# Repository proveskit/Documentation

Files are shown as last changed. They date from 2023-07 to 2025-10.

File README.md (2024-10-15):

# Documentation
The Official Documentation of the PROVES kit. 

Our documentation is primarily hosted as a readthedocs site using the Material format.

# How to Contribute
Have updates you want to make to the documentation? Just open a new branch and make your desired edits in the `docs` folder. Once you're done just make a pull request back to main to have it reviewed before publishing to the main site. 

🚧👷‍♀️CURRENTLY UNDER CONSTRUCTION👷‍♀️🚧
## kit_part_list
This file illustrates all of the components that are shipped with the PROVES kit
## proves_kit_assembly_guide
This is the full assembly guide of the proves kit (currently under construction and updates, so some information may not apply, while other information may be missing)
## proves_kit_owners_manual
This is the owner's manual that comes with each new PROVES kit and provides information about the kit, as well as maintenance and operation of the satellite.

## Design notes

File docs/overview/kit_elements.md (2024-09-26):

# Elements of the Kit 
There are a few key components of the kit that align with the usual lineup of satellite sub-systems: 

- Structure 
- Electrical Power System
- Flight Controller 
- Communications
- Attitude Determination and Control
- Flight Software 
- Ground Support Systems

!!! "3D Visualizer"
    The team from Northeastern made this really cool [visualization](https://autode.sk/4eVLtiX) of the kit! You can even do an exploded view with it. 

<div class="grid cards" markdown>

-   :material-cube-unfolded:{ .lg .middle } __1U CubeSat Structure__

    ---

    The backbone of the CubeSat! Made out of bent 5052 Aluminum sheet metal, self clinching fasteners, and 3M 2216.
    
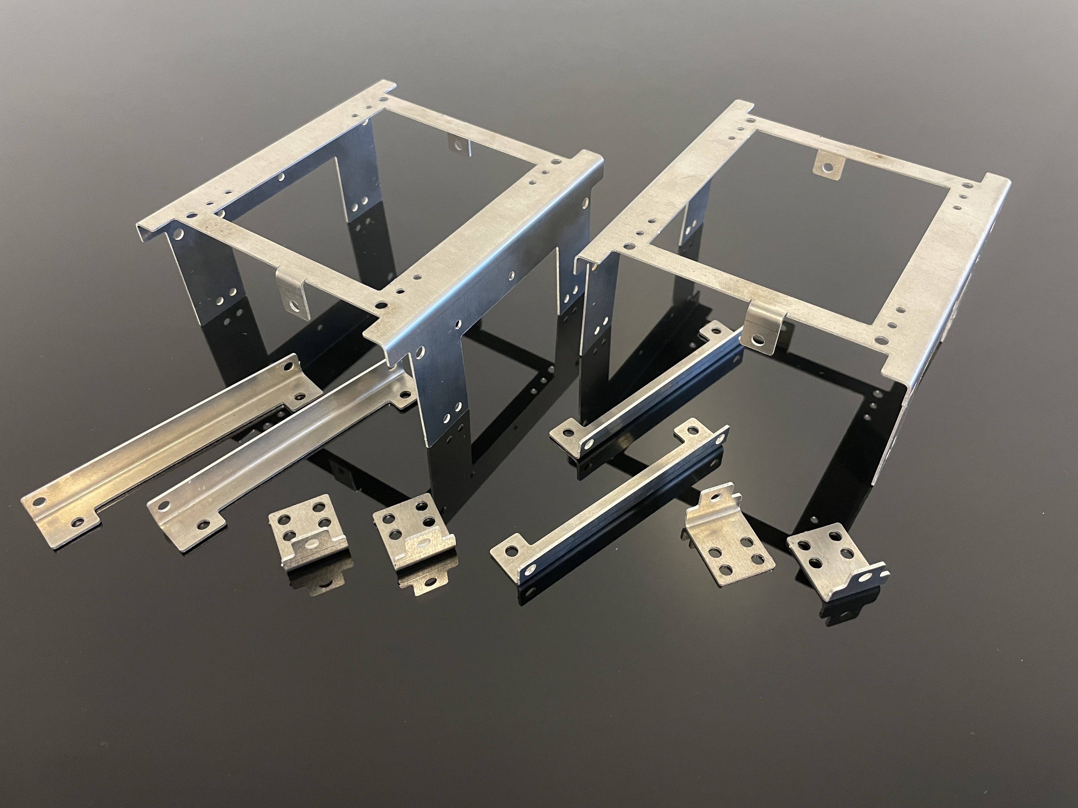
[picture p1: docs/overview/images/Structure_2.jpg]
PROVES Structure
    

    **Status:** V2.1 is Supported! <br>
    V1 has 3x Flight Heritage. 

    [:octicons-arrow-right-24: Core Documentation Link](https://docs.proveskit.space/en/latest/core_documentation/hardware/1U_structure/) <br>
    [:octicons-arrow-right-24: GitHub Repo Link](https://github.com/proveskit/1U_structure)

-   :material-battery-charging-100:{ .lg .middle } __Battery / EPS Board__

    ---

    The Battery / EPS (Electrical Power System) board maintains all of the juice that is needed to run the satellite.
    
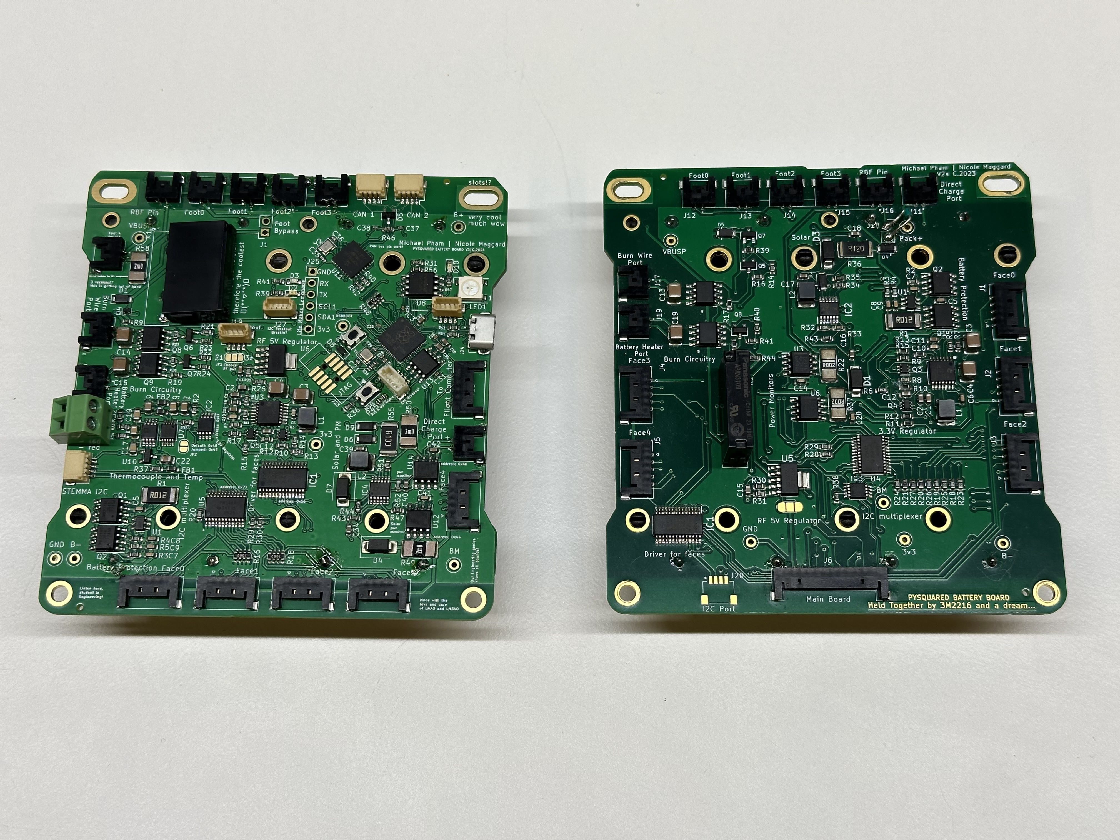
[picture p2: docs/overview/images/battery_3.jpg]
PROVES Battery Board
    

    **Status:** V3a/ V3b / V3c Supported! <br>
    V2 has 2x Flight Heritage. V3 introduces a redundant microcontroller.

    [:octicons-arrow-right-24: Core Documentation Link](https://docs.proveskit.space/en/latest/core_documentation/hardware/battery_board/) <br>
    [:octicons-arrow-right-24: GitHub Repo Link](https://github.com/proveskit/battery_board)

-   :fontawesome-solid-computer:{ .lg .middle } __Internal Flight Controller__

    ---

    The brain of the CubeSat, this is where the radio and main microcontroller lives on an internal board for temperature stability.
    
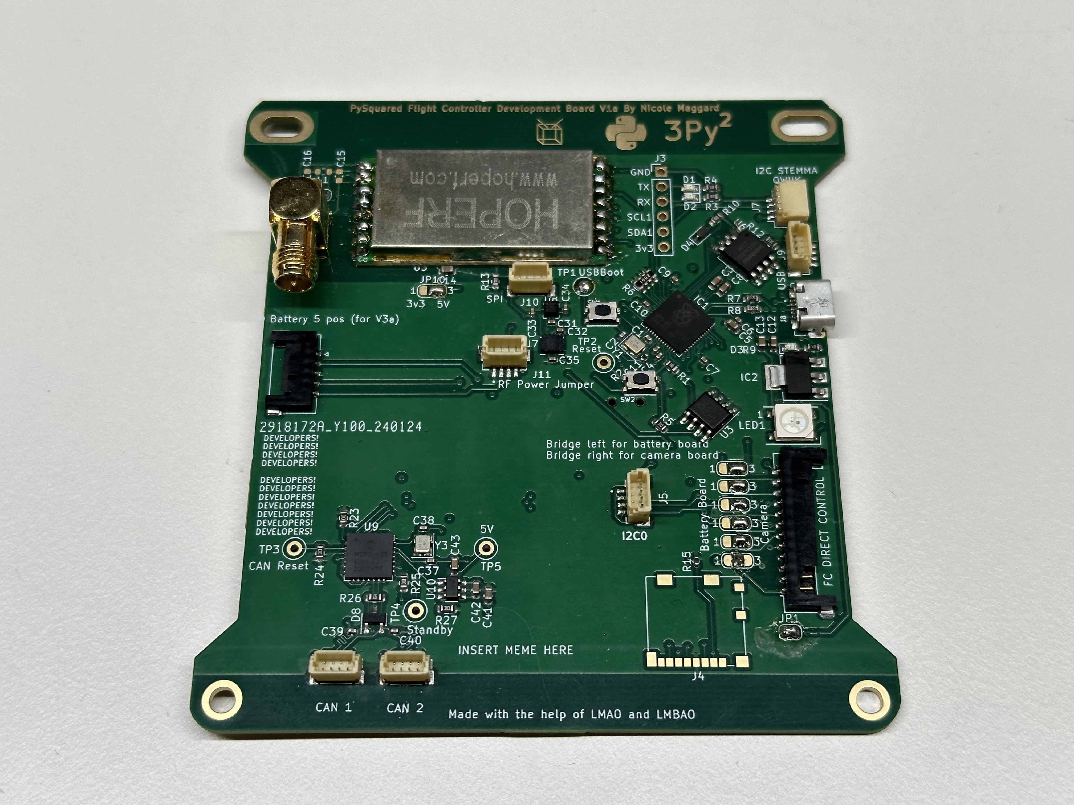
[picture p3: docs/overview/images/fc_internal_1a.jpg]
    

    **Status:** V4a and V4b Supported! <br>
    No Flight Heritage Yet. 

    [:octicons-arrow-right-24: Core Documentation Link](https://docs.proveskit.space/en/latest/core_documentation/hardware/FC_board/) <br>
    [:octicons-arrow-right-24: GitHub Repo Link](https://github.com/proveskit/flight_controller_board)

-   :fontawesome-solid-computer:{ .lg .middle } __External Flight Controller__

    ---

    The brain of the Yearling CubeSats! All mounted on the Z+ endcard of the satellite. Great for education maybe not for flight. 
    
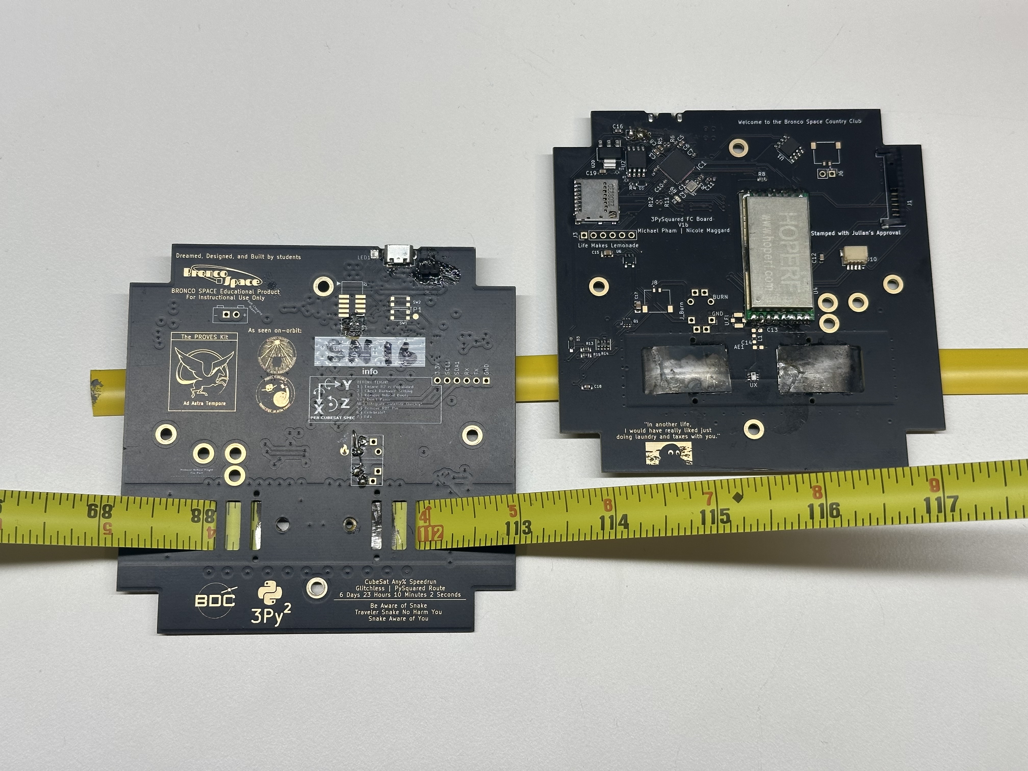
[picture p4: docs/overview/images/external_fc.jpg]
    

    **Status:** V2 is Supported! <br>
    V1 has 2x Flight Heritage. 

    [:octicons-arrow-right-24: Core Documentation Link](https://docs.proveskit.space/en/latest/core_documentation/hardware/FC_board/) <br>
    [:octicons-arrow-right-24: GitHub Repo Link](https://github.com/proveskit/flight_controller_board)

-   :material-solar-power-variant-outline:{ .lg .middle } __XY Solar Board__

    ---

    These are the solar panels that suround the X and Y faces of the CubeSat. They are a common part number for all of the faces to reduce cost!  
    
    PROVES Structure

    **Status:** V1 is Supported! <br>
    V1 has 2x Flight Heritage. 

    [:octicons-arrow-right-24: Core Documentation Link](https://docs.proveskit.space/en/latest/core_documentation/hardware/XY_solar_board/) <br>
    [:octicons-arrow-right-24: GitHub Repo Link](https://github.com/proveskit/solar_boards)

-   :material-solar-power-variant:{ .lg .middle } __Z- Solar Board__

    ---

    The Z- face of the satellite is a little special. It stil collects solar power, so it has cells on it. We also add unique interfacing elements.
    
    PROVES Structure

    **Status:** V2 is In Development! <br>
    V1 has 2x Flight Heritage. 

    [:octicons-arrow-right-24: Core Documentation Link](https://docs.proveskit.space/en/latest/core_documentation/hardware/Z_solar_board/) <br>
    [:octicons-arrow-right-24: GitHub Repo Link](https://github.com/proveskit/solar_boards)

-   :material-clock-fast:{ .lg .middle } __Camera Payload__

    ---

    The backbone of the CubeSat! Made out of bent 5052 Aluminum sheet metal. 
    
    PROVES Structure

    **Status:** V2.1 is Supported! <br>
    V1 has 3x Flight Heritage. 

    [:octicons-arrow-right-24: Core Documentation Link](https://docs.proveskit.space/en/latest/core_documentation/hardware/1U_structure/) <br>
    [:octicons-arrow-right-24: GitHub Repo Link](https://github.com/proveskit/1U_structure)

-   :material-clock-fast:{ .lg .middle } __Mechanisms__

    ---

    The backbone of the CubeSat! Made out of bent 5052 Aluminum sheet metal. 
    
    PROVES Structure

    **Status:** V2.1 is Supported! <br>
    V1 has 3x Flight Heritage. 

    [:octicons-arrow-right-24: Core Documentation Link](https://docs.proveskit.space/en/latest/core_documentation/hardware/1U_structure/) <br>
    [:octicons-arrow-right-24: GitHub Repo Link](https://github.com/proveskit/1U_structure)

</div>

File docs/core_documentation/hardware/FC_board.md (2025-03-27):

# Overview

<p align="center">Figure 1: The Internal Flight Controller Board</p>

The PROVES Kit Flight Controller is part of the PySquared architecture that harbors all of the satellites core operations. There are two variants of the Flight Controller, an internal variant and an external variant.

| Version | Flights | Status |
| --- | --- | --- |
| V0 | Unflown | Not Supported |
| V1 | Pleiades - Yearling, Pleiades - Squared | Legacy Support |
| V2 | Unflown | Unsupported |
| V3 | Unflown | Legacy Support |
| V4a (aka V1a Internal) | Unflown | Supported |
| V4b | Unflown | Supported |
| V4c | Pleiades - Orpheus | Supported |
| V5 | Unflown | In Development |

## Getting Started
!!! note 
    These instructions are valid for Flight Controller Boards V1a (Internal), V4a, V4b. V4c. 

1. If you do not plan on connecting a battery board, ensure that the ```JP1``` solder jumper is connected to enable powering the board via USB.
2. Solder on the Radio Module and an antenna or compatible SMA connector as needed.
3. Solder the JP10 V_RF Power selector as desired. 
    - Bridge the center pad to left for 3.3V or right for 5V. 
    - Generally, the smaller (more square) radio modules require 3.3V whereas the larger (more rectangle) radio modules require 5V. 
4. Plug in a USB Cable!
5. If a CircuitPython file system does not appear, you may have to flash the board with firmware. 
    - The most up to date firmware can be found [here](https://github.com/proveskit/flight_controller_board/tree/main/Firmware). 
    - If you have never installed CircuitPython before you can find instructions [here](https://learn.adafruit.com/welcome-to-circuitpython/installing-circuitpython).
6. Continue to the [PROVES Quick Start Guide](https://docs.proveskit.space/en/latest/quick_start/proves_quick_start/) for more!

## Utilized Parts

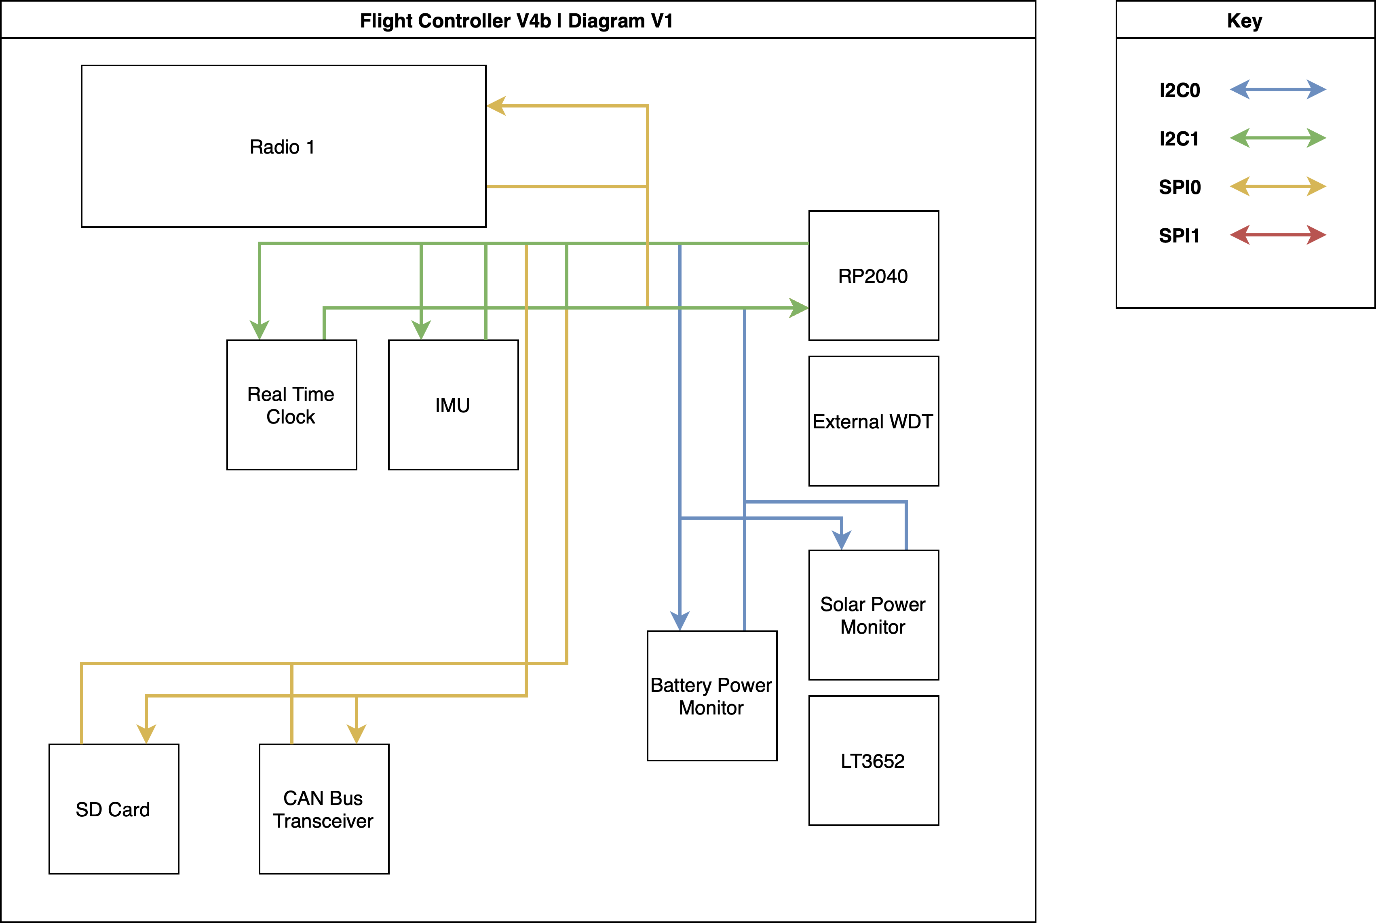
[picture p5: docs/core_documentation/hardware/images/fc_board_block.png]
Block Diagram


#### V4b Schematic
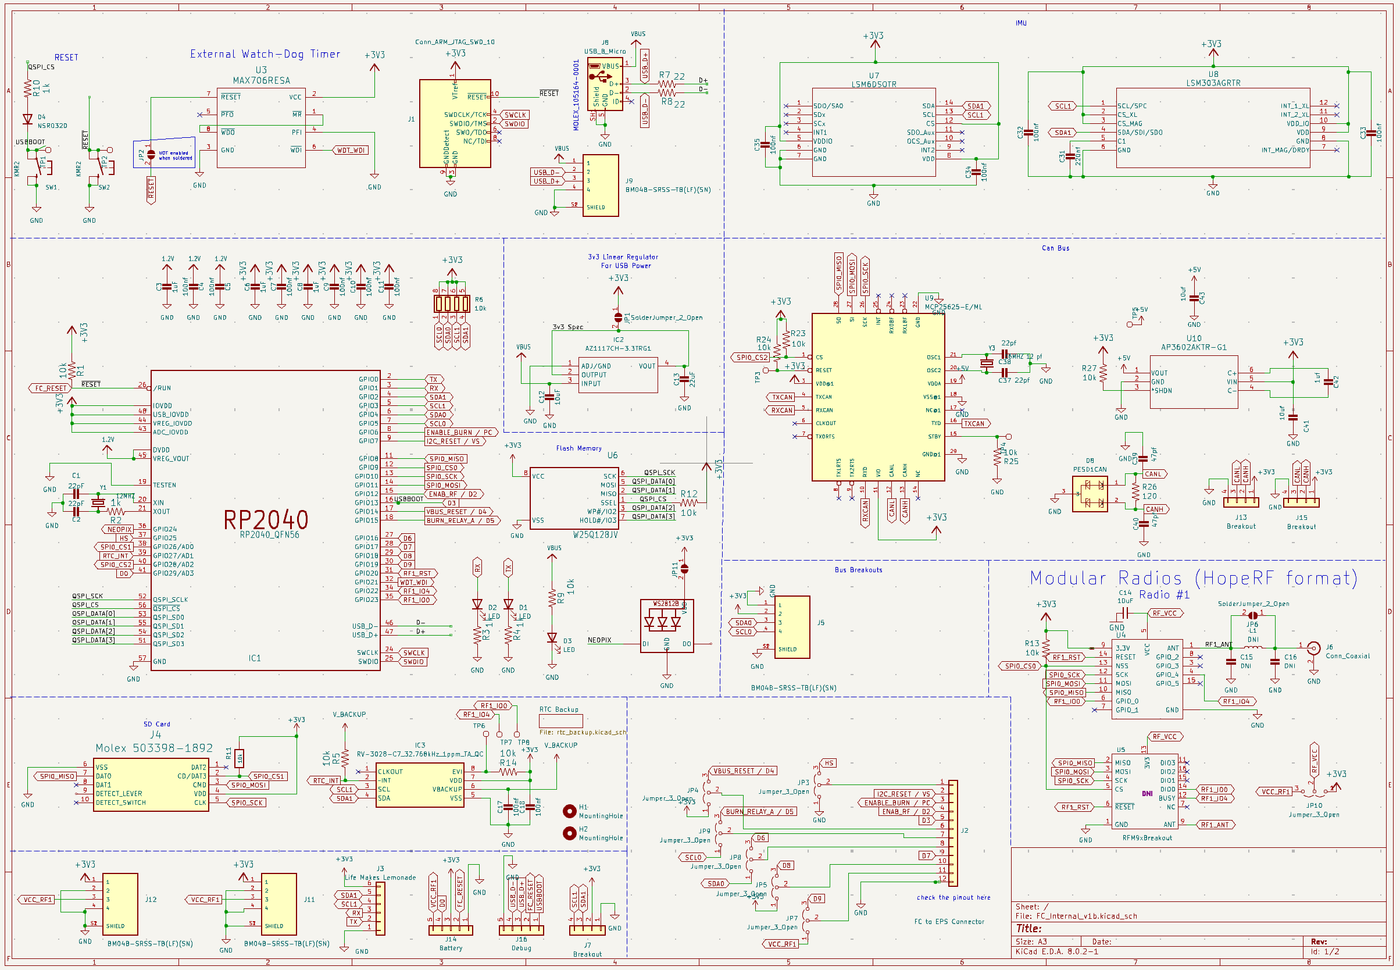
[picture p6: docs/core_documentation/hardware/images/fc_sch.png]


#### V4b Layout
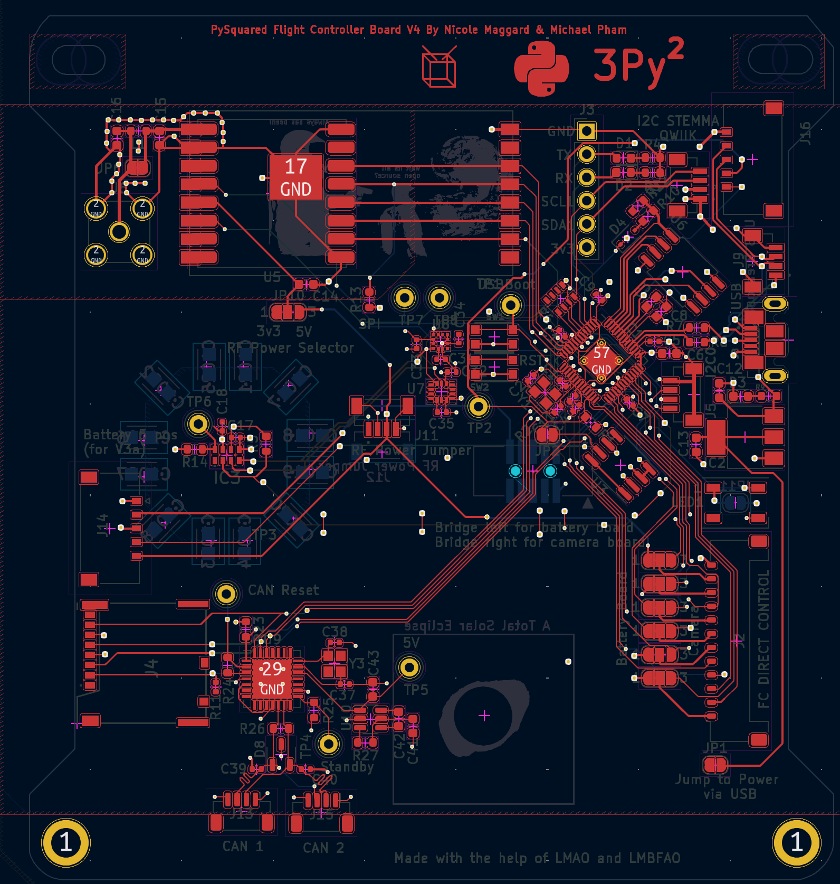
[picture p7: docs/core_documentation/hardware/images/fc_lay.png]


### RP2040 Microcontroller
The RP2040 is a powerful and versatile microcontroller developed by Raspberry Pi Ltd. It features a dual-core ARM Cortex-M0+ processor running at 133 MHz, 264 KB of SRAM, and flexible digital interfaces. The RP2040 was selected for use in the PROVES Kit thanks to its industry leading $1 price and abundance during the global chip shortage. Today we continue to use it thanks to the growing community of users worldwide. 

Key features of the RP2040 include:

- Dual-core ARM Cortex-M0+ processor
- 264 KB of on-chip SRAM
- Support for up to 16 MB of off-chip flash memory
- Programmable I/O (PIO) blocks for flexible interfacing
- USB 1.1 host and device support
- Low power consumption

The RP2040 can be programmed using various languages, including C, C++, MicroPython, and CircuitPython. Currently we support programming in CircuitPython or C++ (through the PicoSDK). 

### RFM98PW 433 MHZ Radio Module
To communicate between satellites or to ground stations. This module was selected based on its flight heritage on the PyCubed lineage of CubeSats. The RFM98 specifically supports the 435Mhz - 438Mhz range that is allocated to amateur radio satellites. The footprint on the board is a hybrid footprint that also allows the mounting of an RFM95 radio module that can operate in the ISM 915Mhz band as well. 

### RV-3028-C7 Real Time Clock (RTC)
The RV-3028-C7 is an I2C connected real time clock module that provides UNIX time in seconds, minutes, hours, date, month, year and weekday counters. The RTC also has the ability to deliver microcontroller interupts based on a predetermined time or through an external event. The primary use case for the RTC onboard the flight controller board will be for pin alarms that can be used to either wake up the microcontroller from a preset sleep period or alert the microcontroller to send a radio message on a predetermined schedule. This is the same IC as the RTC used on the OreSat C3. 

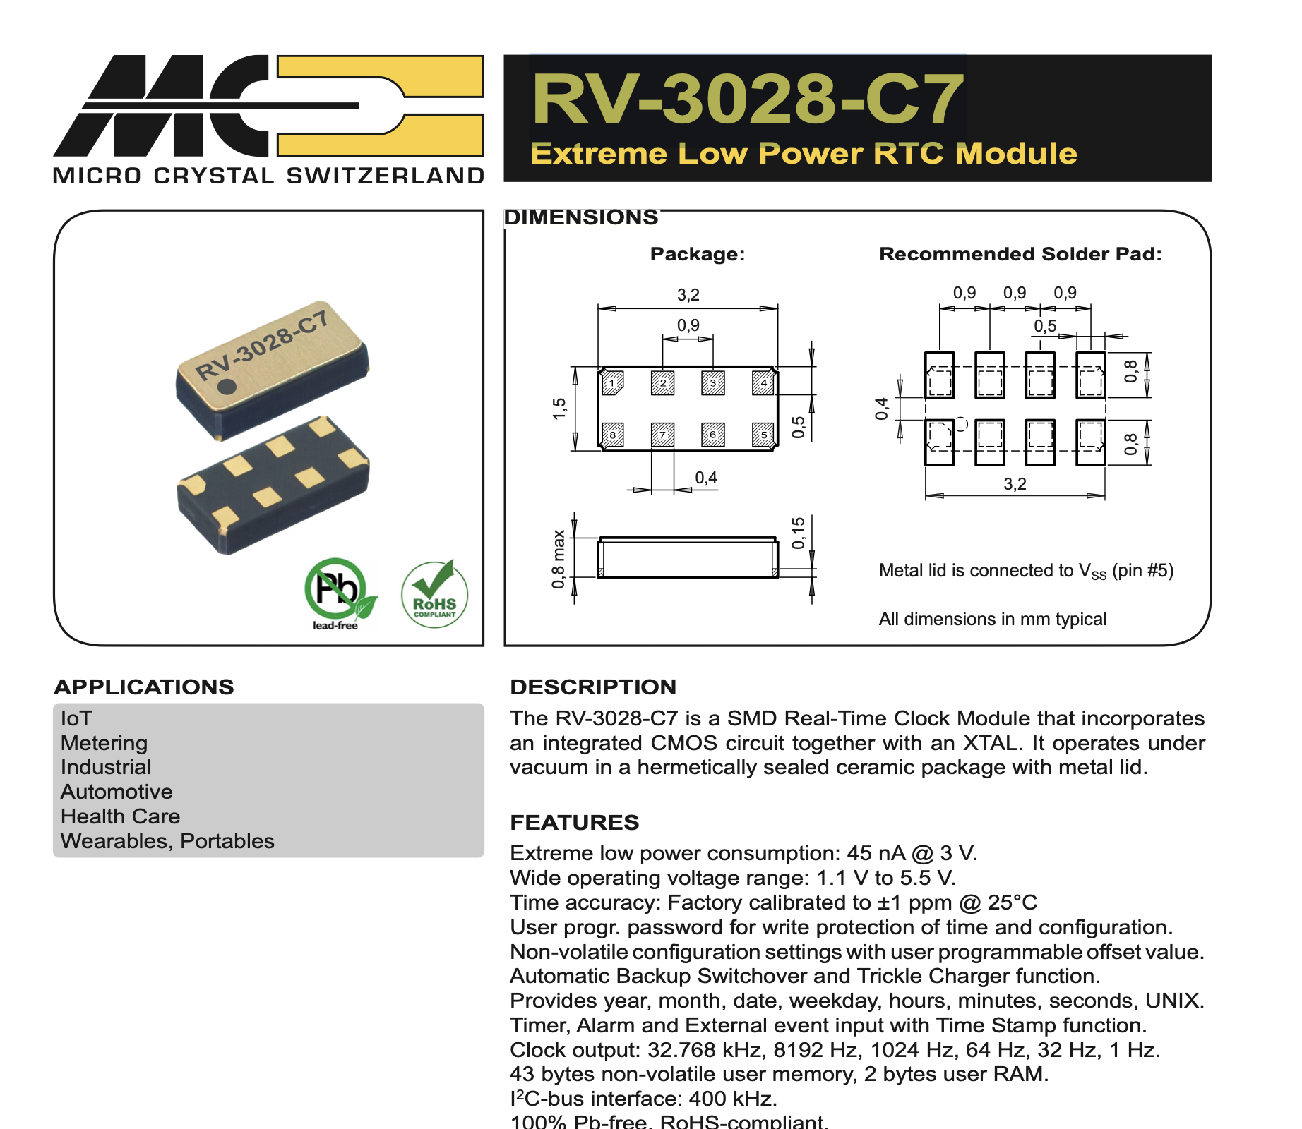
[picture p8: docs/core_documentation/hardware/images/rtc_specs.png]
RTC Spec Sheet


[Datasheet](https://www.microcrystal.com/fileadmin/Media/Products/RTC/Datasheet/RV-3028-C7.pdf)

[Application Guide](https://www.microcrystal.com/fileadmin/Media/Products/RTC/App.Manual/RV-3028-C7_App-Manual.pdf) 

Blake from the TXST Space Lab did some cool testing to make sure that the RTC doesn't start drifting from real time in this [GitHub Issue](https://github.com/proveskit/pysquared/issues/186)

### VL6180 LiDAR
To detect antenna deployment. As of V4 of the flight controller board the VL6180 is instead connected to the battery board to work in concert with the burn wire circuit. 

### MOLEX Micro SD Card Reader
Any SD Card up to 16Gb is supported by CircuitPython. We recommend using [Sandisk Industrial SD Cards](https://www.mouser.com/datasheet/2/669/SanDisk_Industrial%20Grade%20SD%20%20MicroSD%20Product%20Brief-805940.pdf) for flight, but any SD card will do for ground testing. 

### MAX706RESA Watch Dog Timer
To ensure the Flight Controller stays operational, this is a component that is borrowed from the PyCubed and is the watchdog circuit for V4b and earlier flight controller boards.

### TLV1704 Radiation Tolerant Watchdog Circuit
[Datasheet](https://www.ti.com/lit/ds/symlink/tlv1704.pdf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)
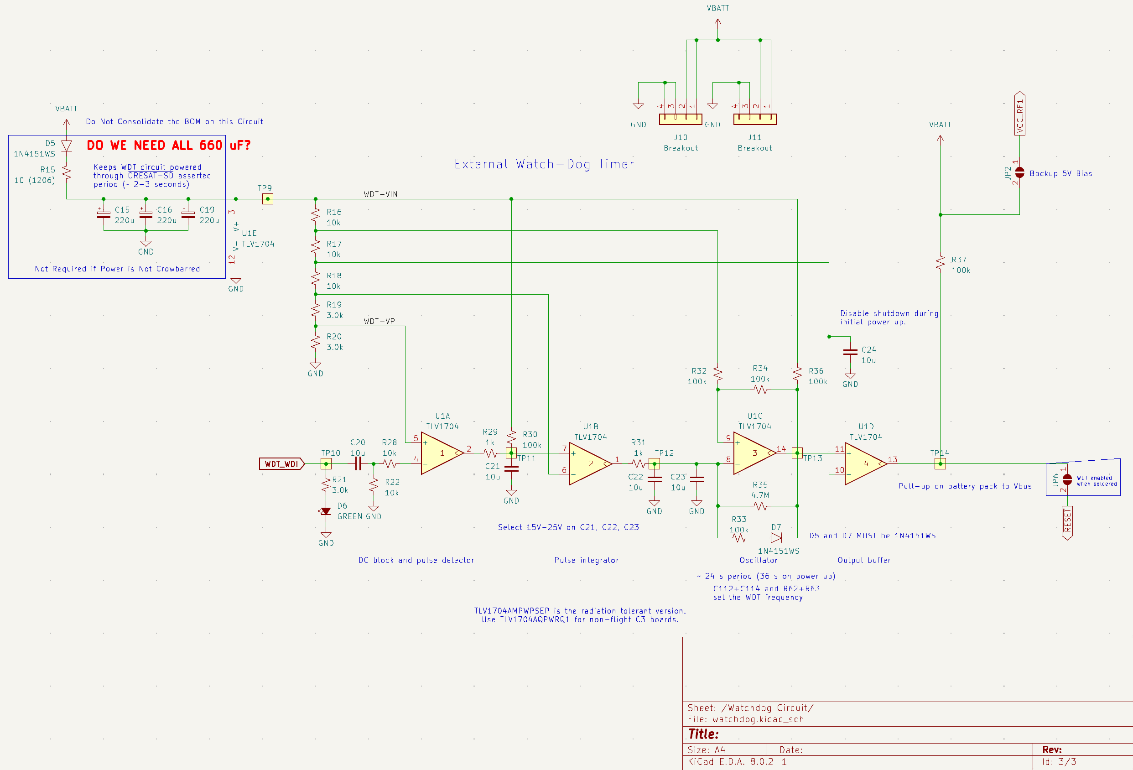
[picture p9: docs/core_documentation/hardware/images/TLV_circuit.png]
TLV Circuit Schematic


Starting with **FC Board V4c** and higher we swapped out the MAX706RESA with a windowed watchdog circuit based on the TLV1704 comparator network from Ti. This particular design has the option of swapping the standard TLV1704 with a TLV1704 **-SEP** (Space Enhanced Part) which is radiation tolerant (note there is a difference between *tolerant* and *hardened*). 

#### Using the Watchdog Circuit
By default this watchdog circuit expects a voltage pulse along the `WDT_WDI` line from the RP2040 every 26s (or 54s on cold start). If no pulse comes through then a reset will be triggered by pulling the `RESET` line low. 

!!! bug "V4c InspireFly Special Triggers too Fast!"
    
    A known issue for V4c InspireFly Special boards is that when powered up the WDT circuit actually triggers a reset approximately every 5s rather than the designed 26s. This was due to a BoM consolidation mistake when manufacturing the boards and will be corrected in future production runs.

    Find out more on [this GitHub Issue](https://github.com/proveskit/flight_controller_board/issues/24).

In order for that `RESET` signal to actually be sent, a bias voltage (5V or greater) must be provided through the `J10` or `J11` breakout connectors. For the signal to actually make it through to the RP2040, then the JP6 solder jumper on the front of the FC board needs to be connected. 

### AZ1117CH 3.3V Linear Voltage Regulator
To power the Flight Controller without a Battery Board. This linear regulator uses the 5V V_Bus line from the USB port and supplies 3.3V when the JP1 solder jumper is connected.

## Change Log
The change log keeps track of major differences between the various versions of the flight controller board. 

### Version 4
With the introduction of V4 Flight Controller Boards (also known as V1 Internal Flight Controller Boards) we moved the main flight controller from being the inside of an exterior panel to its own dedicated board on the inside of the satellite. This was done to better protect the main avionics package from thermal and radiation effects. 

#### V4a
The `a` variant of the flight controller board introduced some layout changes and part package swaps from the base V4. No fundamental functionality was changed in this version. 

#### V4b
The `b` variant of the board repositioned certain connectors, added a debug Picolock, variant added a Real Time Clock circuit to the board. 

#### V4c 
The `c` variant of the board adds the OreSat based watchdog timer circuit to try and better defend against radiation upsets. There are two sub-varients of this board which are the `Express` (as seen on Pleiades - Orpheus) and `InspireFly Special` (as seen on InspireFly). 

## Power Consumption Characterization
Notes on the FC board power consumption and attempts to reduce power consumption through underclocking the MPU are noted in [this GitHub Issue](https://github.com/proveskit/flight_controller_board/issues/22).

## Known Issues
- Microcontroller and radio possibility have a high suspectibility failure due to thermal and radiation effects. In a future version imrpoved placement and redundancy will be implemented to protect these core components from those effects.  
- Antennas are very annoying to install and may also be suceptible to failure due to thermal effects. 

### V5 Dev Board Errata

- LM2901 needs to the the B variant for open collector use
    - When the watchdog load switch is enabled it causes a hard reset of the board
- SPI1 and SPI0 are using the same hardware peripheral whoops
- For a currently unknown reason the load switches go into FAULT when connected to the solar panel boards
    - The solar panels function without overcurrent when powered by an independent supply
    - Removing the current limit resistor seems to have no effect
    - This is now SOLVED. Current limit is pulled up instead of down
- MUX_RESET is not connected
- When solar face is power cycled quickly it latches the TCA I2C bus low. Requires an unplug and replug
- Fire Deploy A and Fire Deploy B need to be connected to burn.
- 555 Timer Reset Circuit creates a boot loop when used.

## Troubleshooting

## Serial Number Tracking 

- FCV4c_0010: RFM98PW Sent to InspireFly
- FCV4c_0011: RFM98PW Sent to InspireFly
- FCV4c_0016: RMF98PW Sent to InSpireFly with -SEP Watchdog
- FCV4c_0006: RFM98PW Sent to Texas State
- FCV4c_0008: RFM98PW Sent to SlugSat
- FCV4c_0009: RFM98PW Sent to Northeastern
- FCV4c_0012: RFM98PW Sent to Columbia
- FCV4c_0017: No Radio Sent to Mt. SAC

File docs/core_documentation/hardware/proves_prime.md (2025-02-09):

# The PROVES Prime Mainboard
Trying out a single board implementation for the PROVES Kit again! 

## Design Objectives
The core goal of the PROVES Kit is to provide a low cost and accessible means of getting working hardware and software in outer space. We interpret that goal as the following:  
```
Having a satellite architecture that:
- Costs approximately $1000 
- Can be built in one day and 
- Will die when it deorbits. 
```
Depending on how the Pleiades - Orpheus mission goes, V1.5 of the kit may have already acomplished that! There is a big problem with V1.5 though, technical debt from patchwork development over the last year has made it rather complicated and not easy to replicate outside of the Bronco Space Lab. As a result, here we are trying to semi clean sheet a V2 design of the kit for much quicker and easier builds! 

## Planned Changes From V1.5 

Major Updates: 
- Returning to a PyCubed Style Mainboard / Battery Board Scheme 
- Removing the secondary microcontroller 
- Reworking the electrical power subsystem
- Adding options for multi-radio setup 
- Rework of the connectors and harnessing system 
- Designing for scalability with larger and more complex payloads

## Dev Logs
This section is for a running log of development activities! The goal is with regular "dev diary" sort of updates to be able to track the logic behind alot of the PROVES Prime Design Decisions. 

### February 9, 2025 | Expanding on the Minimum Viable Satellite
It has been a couple slower than expected weeks for development! The main thing we have to share at this point is that we've slightly refined what we are thinking of when we talk about the MVS. The attatched block diagram helps explain what our current thinking is.

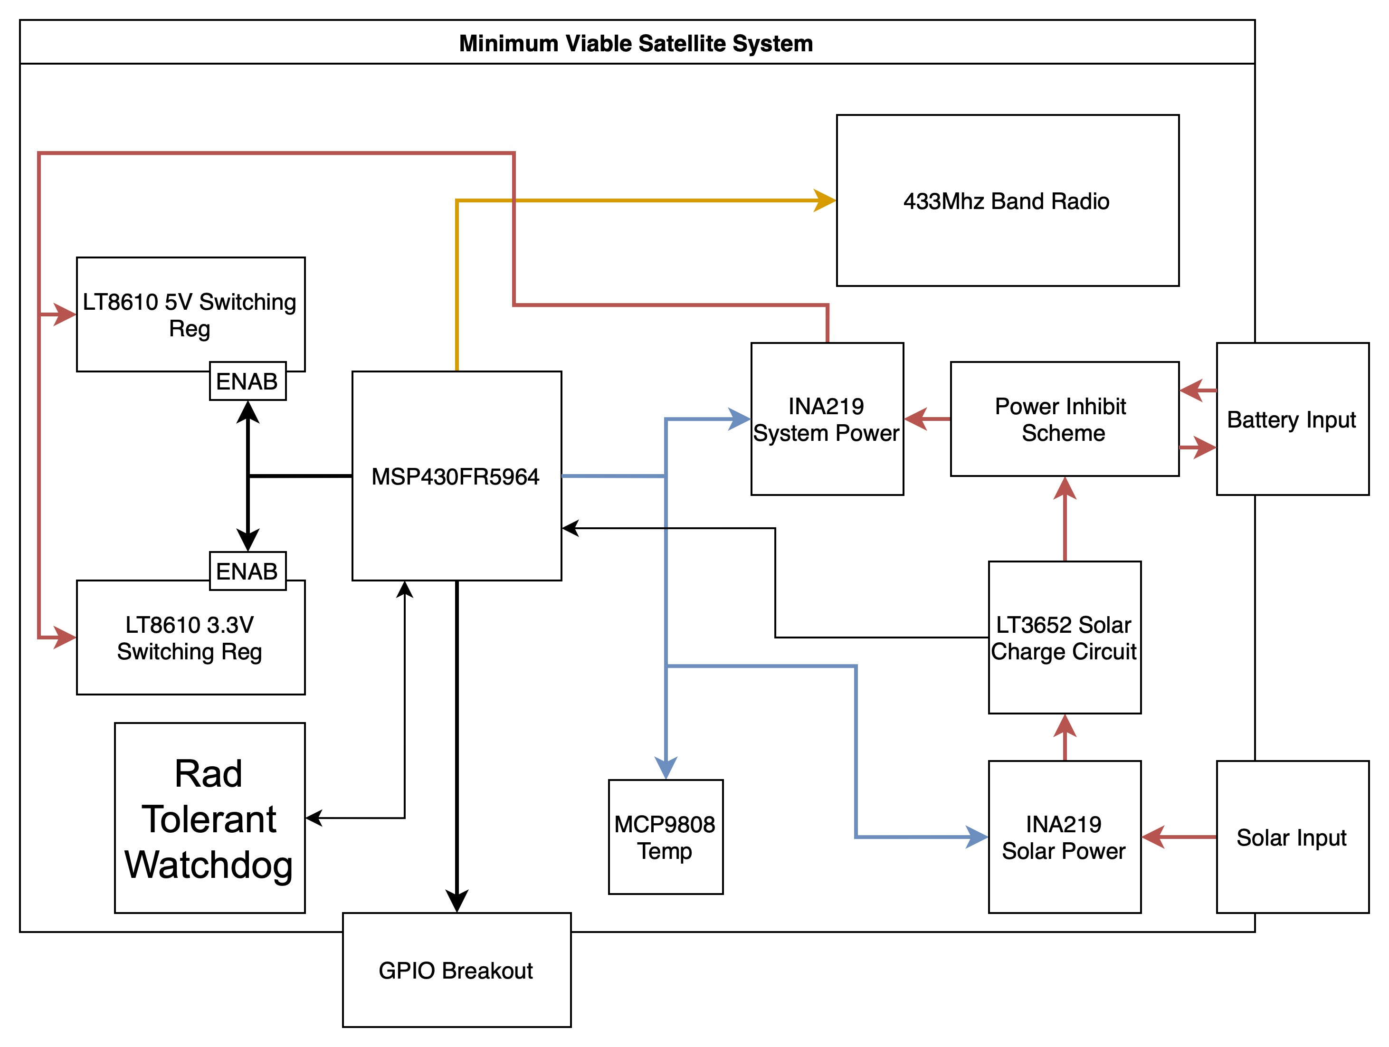
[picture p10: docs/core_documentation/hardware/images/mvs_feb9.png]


The general concept here is that the MSP430RF used at the core of the MVS system will have the ability to monitor and manipulate the overall power distribution to the rest of the satellite system using its GPIO. In a way, this chip is now going to be the supervisor that ensures all of the satellite's subsystems are behaving. Having this be a seperate chip rather than rolling it into the RP2350 frees up I/O and simplifies the software that needs to run on the RP2350 so it can focus on the mission needs rather than satellite oversight.

### January 26, 2025 | The First Devlog! 
Okay so this is where we're starting with trying to actively track the development of this board! Currently the two design contributors are Michael Pham, Rachel Rakushkin, and the Hacker LMBFAO. At this stage we have some preliminary component select and schematic migration from the existing PROVES boards complete. 

#### Overall Architecture Plan
Right now our thought is to run a hybrid architecture where there is a ultra-low power microcontroller (the MSP430FR line most likely) that runs a "Minimum Viable Satellite" (MVS) alongside an RP2350 microcontroller that will run most of the satellite systems and interface with payload data collection. The attatched block diagram reflects the thinking here. 

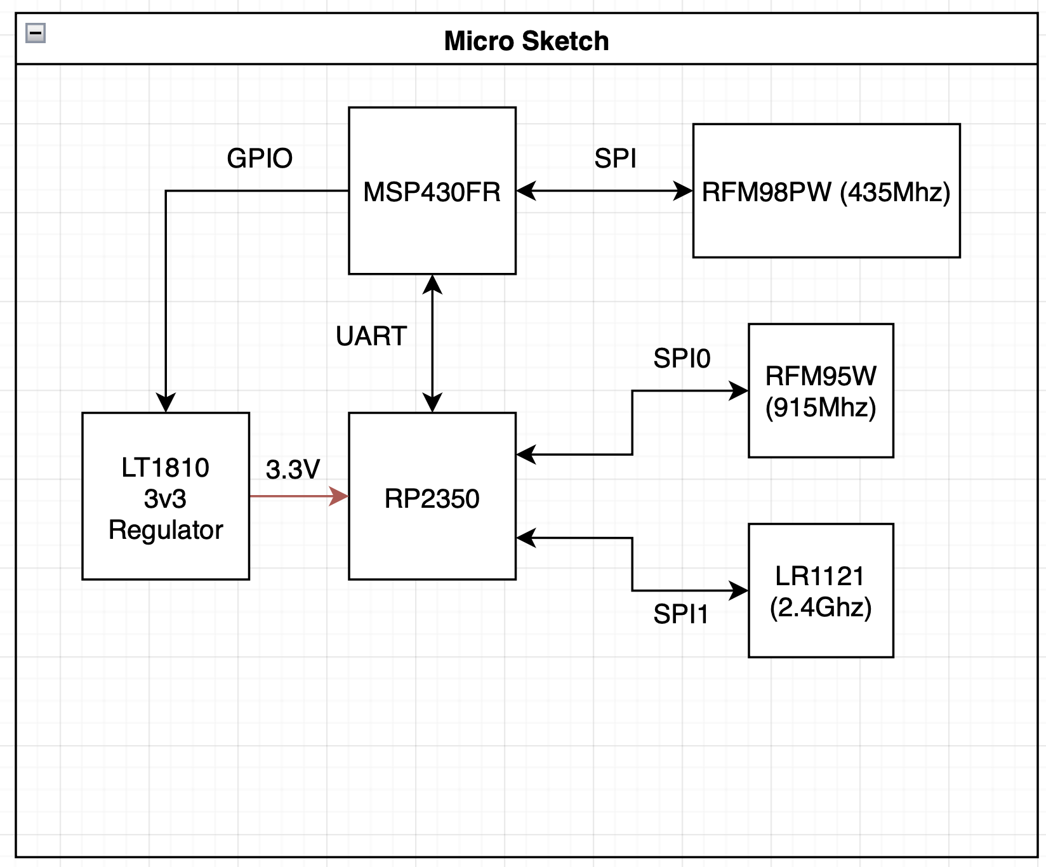
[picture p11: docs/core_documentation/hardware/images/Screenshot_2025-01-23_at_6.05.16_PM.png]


The big idea here is that we have a somewhat modular MVS section of the board, that is able to support the most essential satellite systems in the safest and simplest way possible, running alongside the core systems connected to the RP2350, which will do all of the mission data collection and satellite management. The thought is that we can rely on the MVS at all times to provide a satellite beacon with the most important satellite metadata while allowing the core systems to run a little more fast and loose with the RP2350.  

The MSP430 (despite being a pretty ancient microcontroller) has plenty of proven heritage in spaceflight and industrial applications. Particularly the **FR** varients use FRAM which lends an increased resistance to radiation upsets and permits the microcontroller to run a very low power. As a center of the MVS, this microcontroler will have access to the 435Mhz band UHF radio, the system and solar power monitors, and GPIO that connects to the enable pins of the 3v3 and 5v regulators. That last element giving the MVS the ability to "turn the sateliite off and on again" if it is ever needed. This system will then interface with the RP2350 core through a UART connection. 

#### LT8610 Switching Voltage Regulator Designs
One of the other big changes from all previous PROVES Kits is that we leaving behind the TPS5422X series of switching voltage regulators and instead using the LT8610 series. We get a minor improvement in efficiency and compactness by doing this, but one of the biggest reasons we are making this switch is because there seems to be pretty promising raditation data from ESA on these chips!

[Link to ESA Radiation Database](https://esarad.esa.int/)

Rachel led the design of both the 3.3V and 5V switching regulator schematics. The preliminary schematics are attatched here. 

[!Rachel's Schematics](images/lt8610_jan.PNG)

## Quick References
This is a section for storing quick reference images and notes regarding the design of the PROVES Prime Mainboard. 

### RP2350 Pin Definitions
!!! "Source"
    https://datasheets.raspberrypi.com/rp2350/rp2350-datasheet.pdf

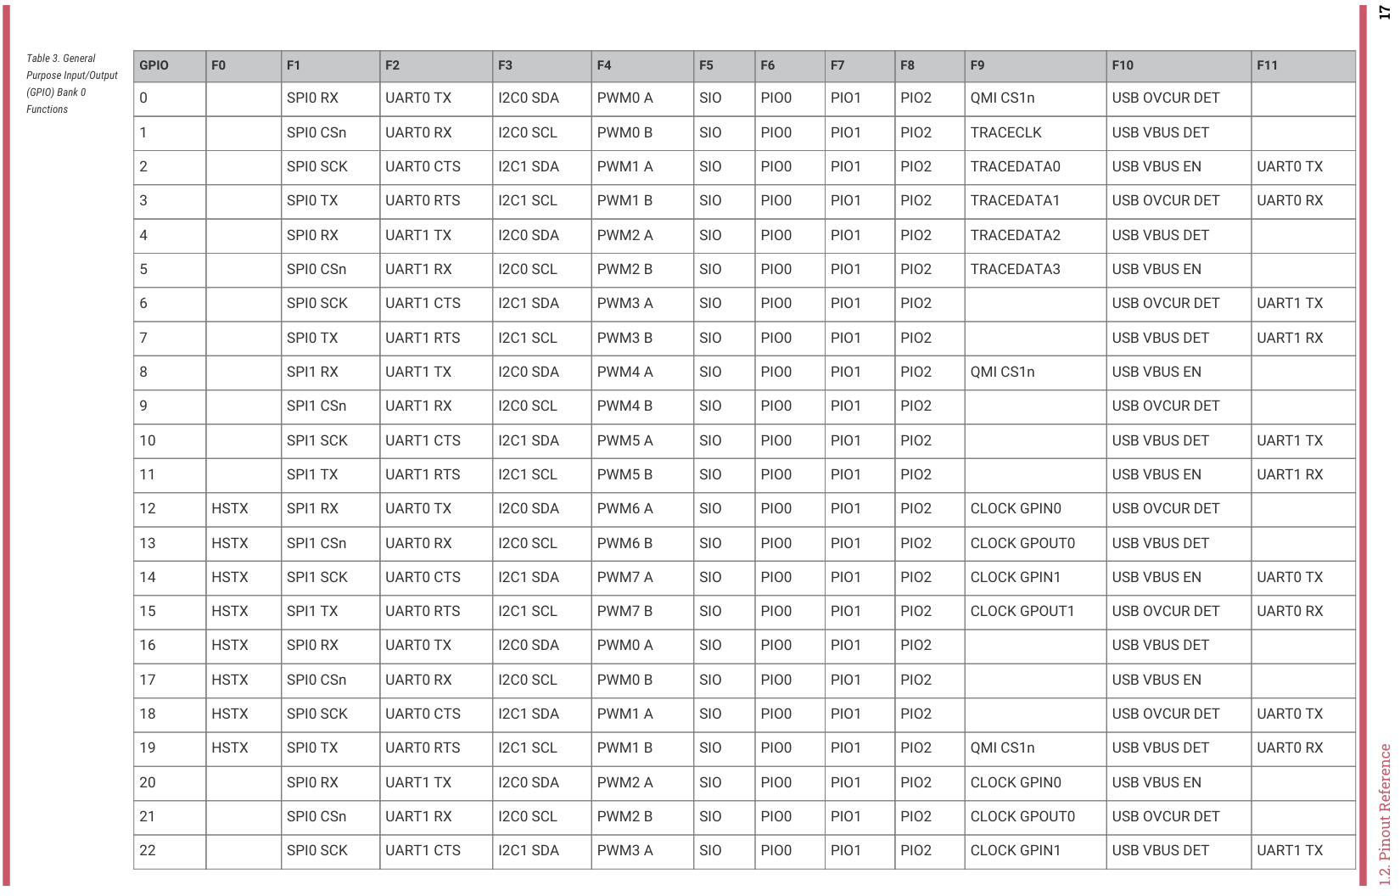
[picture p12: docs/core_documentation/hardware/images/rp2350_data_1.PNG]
RP2350 Pins 1

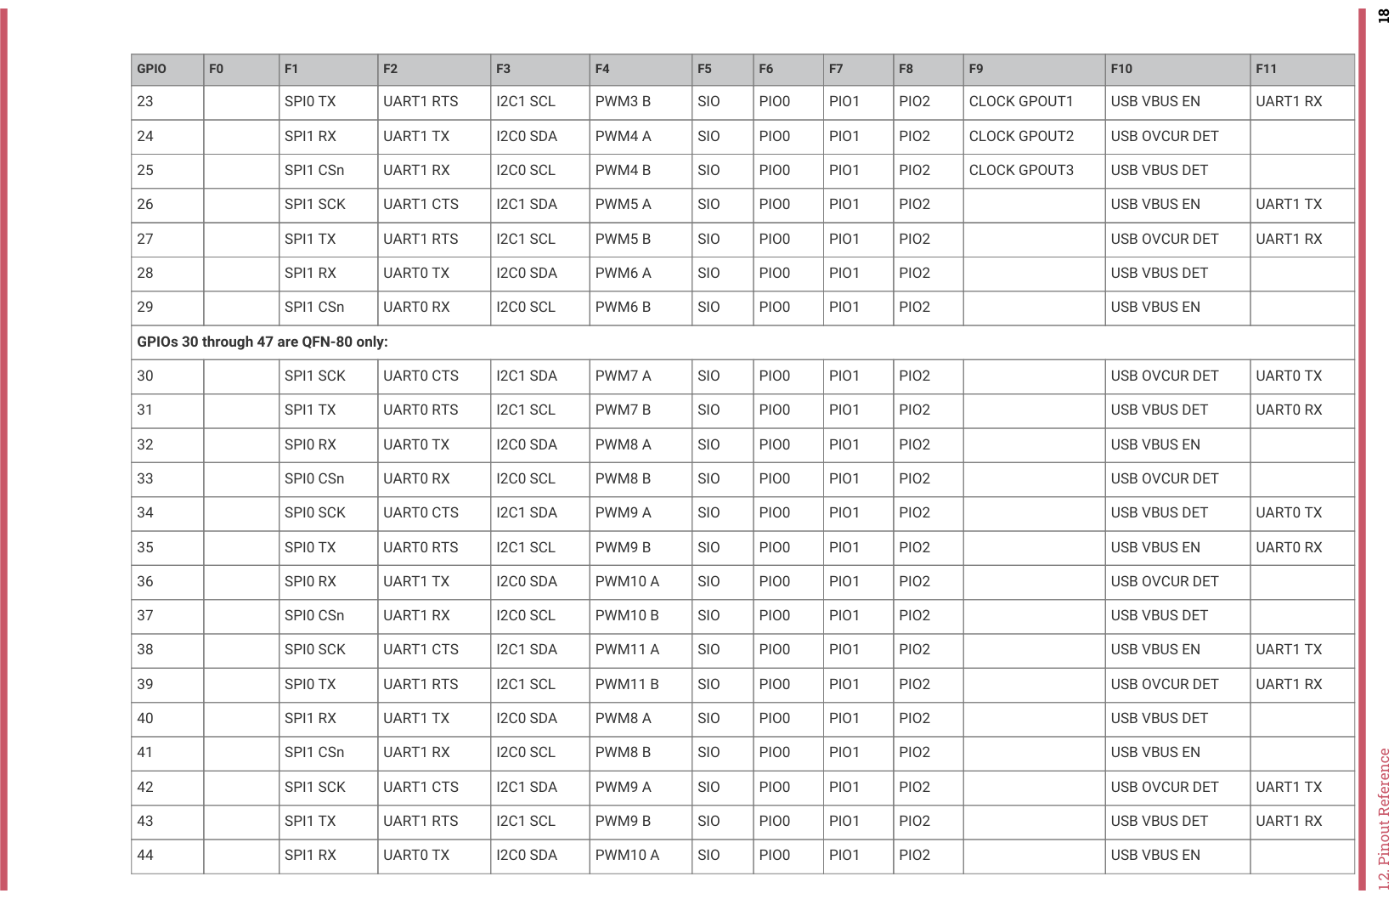
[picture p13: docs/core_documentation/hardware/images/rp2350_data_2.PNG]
RP2350 Pins 2

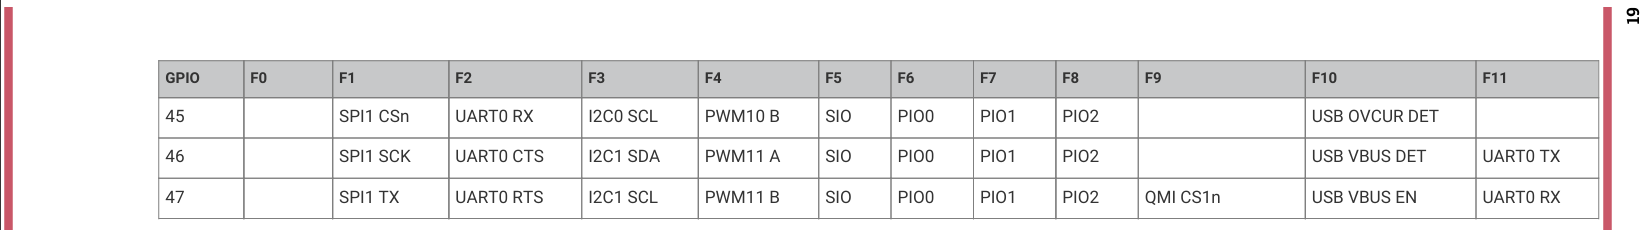
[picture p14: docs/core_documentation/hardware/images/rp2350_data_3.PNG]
RP2350 Pins 3


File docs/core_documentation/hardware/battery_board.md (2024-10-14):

# Overview
!!! tip "Looking for the [GitHub](https://github.com/proveskit/battery_board)?"


<p align="center">Figure 1: The Battery Board V3 (left) and V2 (right)</p>

The PROVES Kit Battery Board was baselined on the PyCubed battery board, but has since evolved into more of a fully fledged EPS board. This is especially true of V3 and V3a which both host their own RP2040 microcontroller.  
## Getting Started
Currently there is one officially supported version of the batery board and one in development version: 

| Version |Flight Heritage| Description |
|---|---|---|
| **V2a** | Pleiades - Yearling 2, Pleiades - Squared | This version contains the core functionalities needed for battery and sensor management. |
| **V3**  | None| This version is a significant overhaul of the battery board, and it implements a RP2040 microcontroller for power management. |
| **V3a**  | None| Removed the multiplexer and LED driver to make way for a switching 5V regulator. |
| **V3b**  | None| More bug fixes over V3a and the first board to be colored red. |
| **V3c**  | None| Changed the thermocouple IC to an SPI chip and added a real time clock. |
 
## Functionalities

```mermaid
graph TD
    A[Start] --> B[Boot Sequence]
    B --> C{Check Power Mode}
    C -->|Critical| D[Critical Power Operations]
    C -->|Low| E[Low Power Operations]
    C -->|Normal| F[Normal Power Operations]
    C -->|Maximum| G[Maximum Power Operations]
    D --> C
    E --> C
    F --> C
    G --> C
```

## Block Diagram
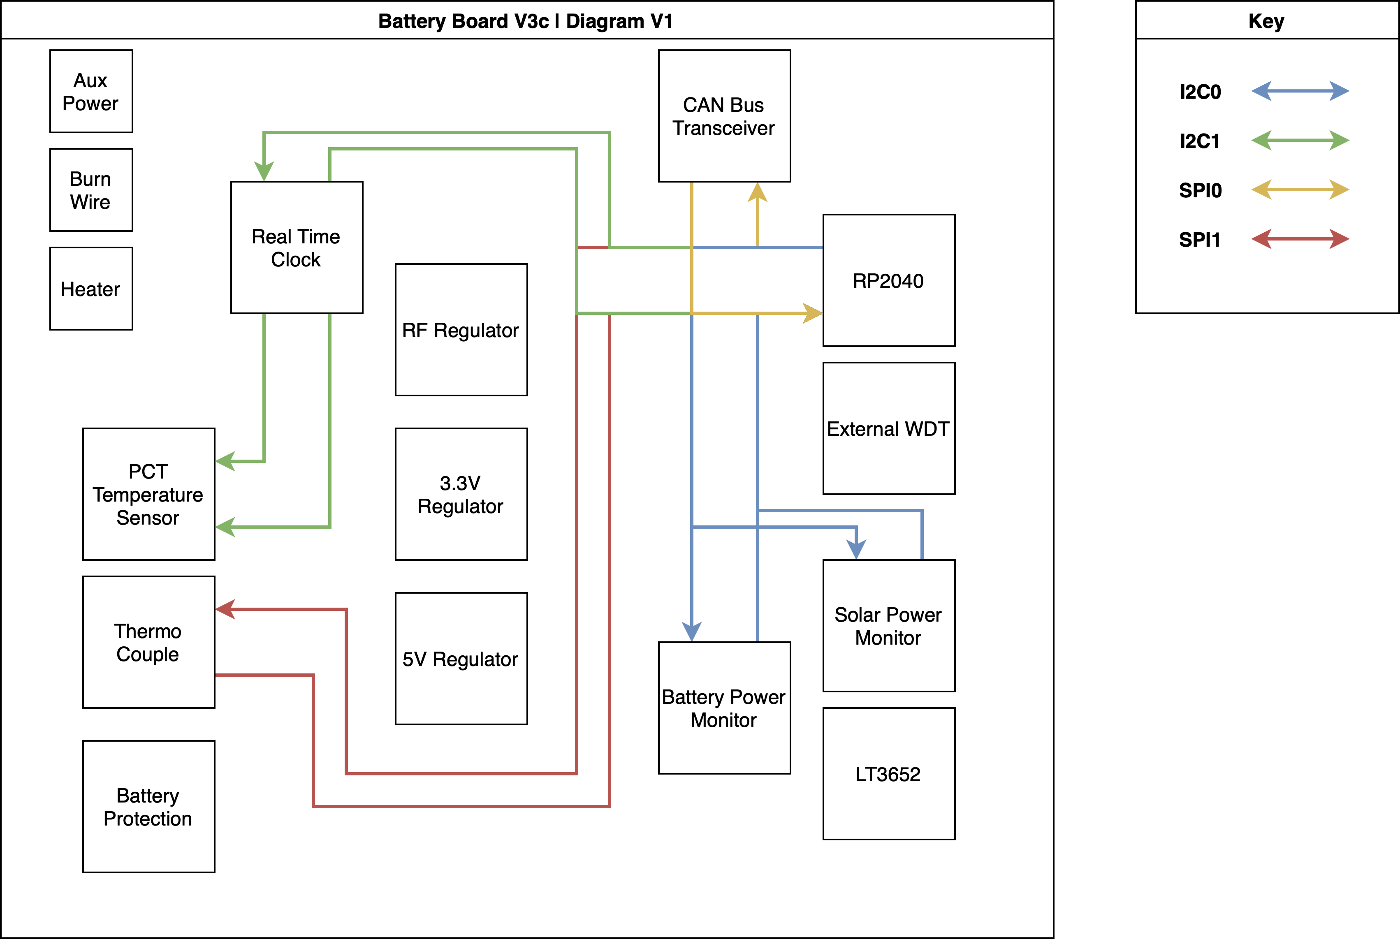
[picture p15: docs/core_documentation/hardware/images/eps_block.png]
EPS Block Diagram


## The Inhibit Scheme 
One of the most important functions of the battery board is to properly inhibit the satellite and ensure that no electrical power flows while it is inside the deployer pod. For this purpose, there are a set of limit switches that can be attatched to the 2pos headers on the battery board that are thrown open when inside a deployer pod to cut off battery power from the satellite. Usually the requirement is only for two inhibits in series, but we use a 2s2p configuration for redundancy. 

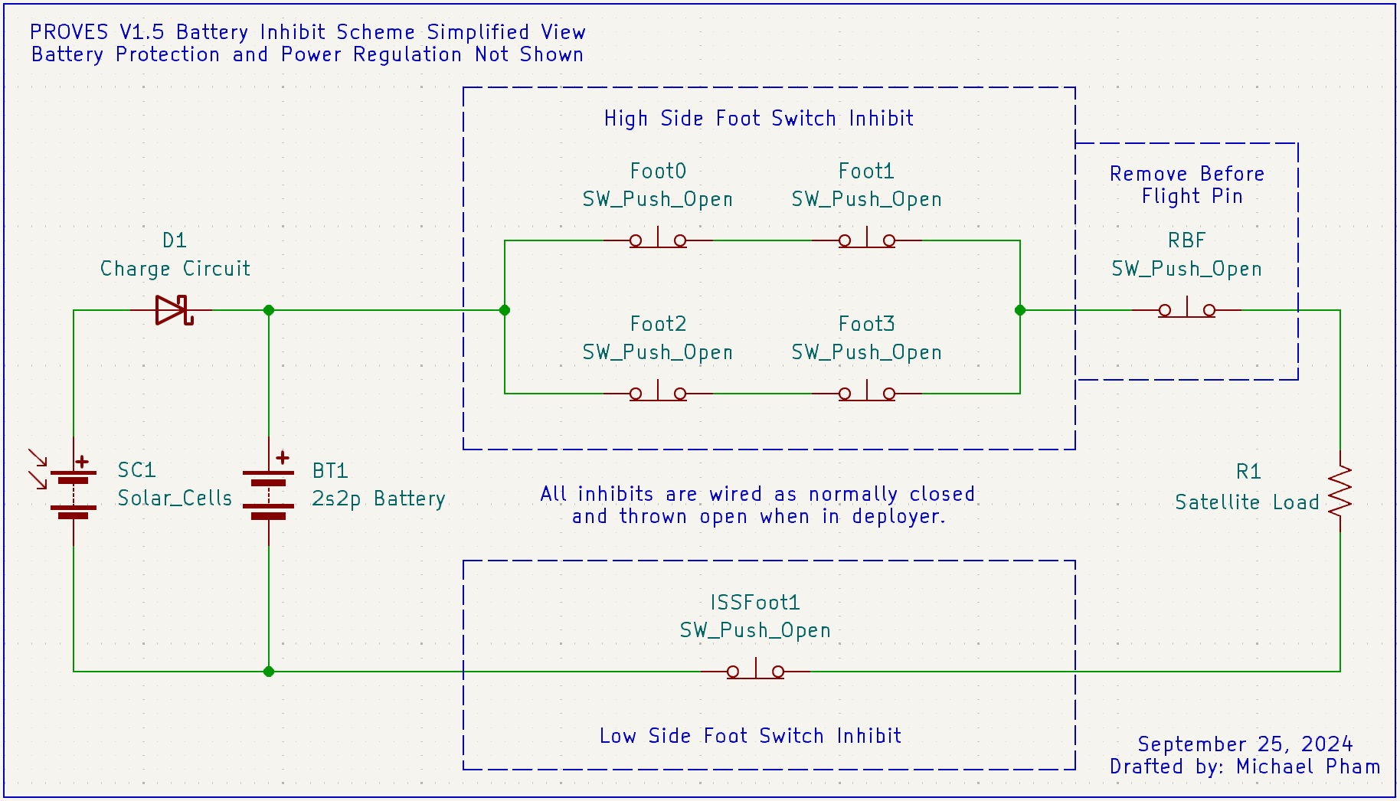
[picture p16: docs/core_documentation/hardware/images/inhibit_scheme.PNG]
Inhibit Diagram


!!! warning
    V2 and earlier battery boards are not ISS compliant as there is no low side inhibit switch that fully isolates the batteries from the rest of the electrical subsystems. 

## Utilized Parts
The battery board flown on the Pleiades-Yearling and Pleiades-Squared missions. The board serves as an interface with the rest of the satellite. A 12 position picolock is utilized to interface between the Flight Controller and the Battery Board. The board interfaces with 5 solar faces of the satellite using 5 position picolocks. The other 2 position picolocks are used for interfacing with the inhibit scheme, battery heater, burn wire, and direct charging port. The hardware utilized on the module is the following:

### LT3652 Solar Charger 
This component is used to charge the satellite's batteries using power harvested from solar panels. This part is not a true MPPT solar charger, but it emulates one. There is debate as to whether true MPPT is worth it on small 1U class satellites due to its extra complexity. In the future we will look towards using the microcontroller on the battery board to manage a true MPPT charging curcuit. 

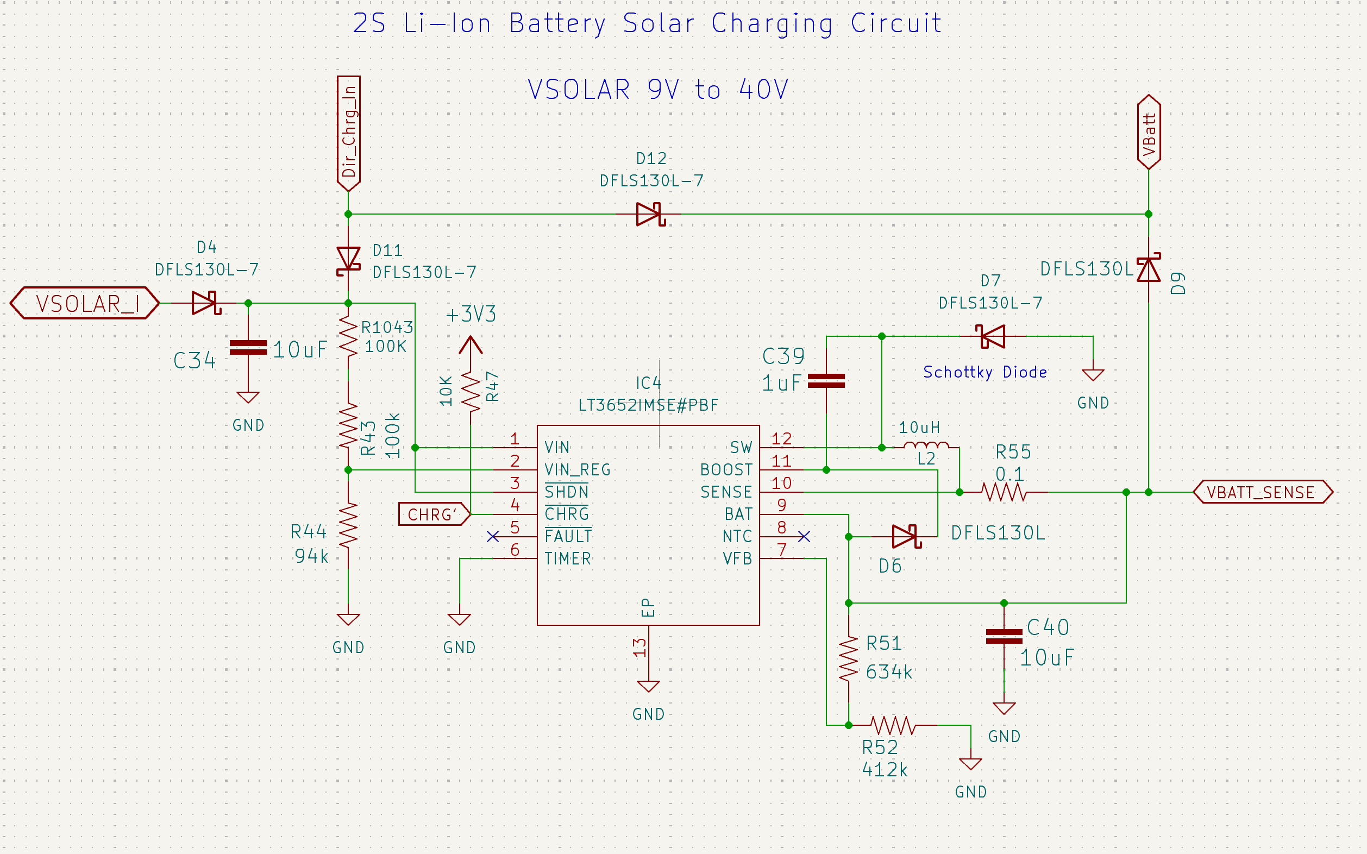
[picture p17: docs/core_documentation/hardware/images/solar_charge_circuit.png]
Solar Charger Circuit

<p align="center">Figure 2: The LT3652 Schematic</p>

### PCA9685 LED Driver
The PCA9685 LED Driver controls the power distribution to the solar faces. It enables selective powering of solar face components, facilitating isolation and power-down of specific faces in case of malfunction, thus protecting the system and conserving energy.

!!! note
    In V3 of the battery board this circuit was moved to the Z- panel of the satellite.

### TCA9548 I2C Multiplexer
The TCA9548 I2C Multiplexer expands a single I2C bus from the flight computer into multiple channels. This design simplifies the communication with multiple sensors on different solar faces while keeping their addresses identical, enhancing the modularity and scalability of the system. The TCA also appears to provide some level of bus protection, so in the case of an I2C sensor failure the fault is limited to only the face that the sensor is on rather than also interupting all other I2C sensors on the satellite. 

!!! note
    In V3 of the battery board this circuit was moved to the Z- panel of the satellite.

### TPS54226PWP Switching Voltage Regulator
These two Switching Voltage Regulators are the primary regulator for supplying the microcontroller and sensors onboard the satellite. They creates a stable 3.3V and 5V power supply from the variable battery voltage, and its "One Shot" Regulator Reset feature provides a way to reset the power bus, aiding in system recovery and fault tolerance. This part is borrowed from Max Holliday's PyCubed, and is believed to be slightly more radiation tolerant than other switching regulators due to there being a radiation hardened version in the part family. 

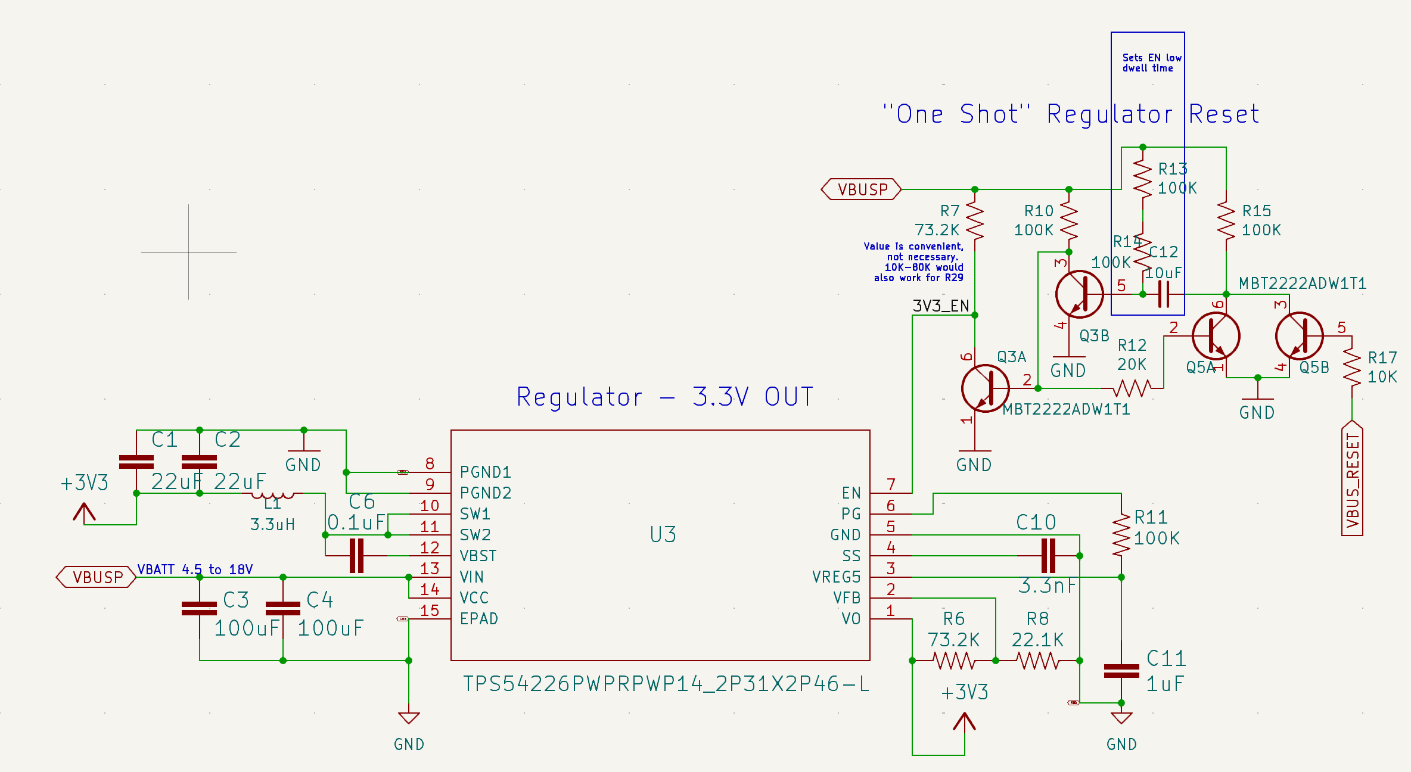
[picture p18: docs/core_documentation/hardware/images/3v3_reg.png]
3.3V Regulator Circuit

<p align="center">Figure 3: The 3.3V Regulator Schematic</p>

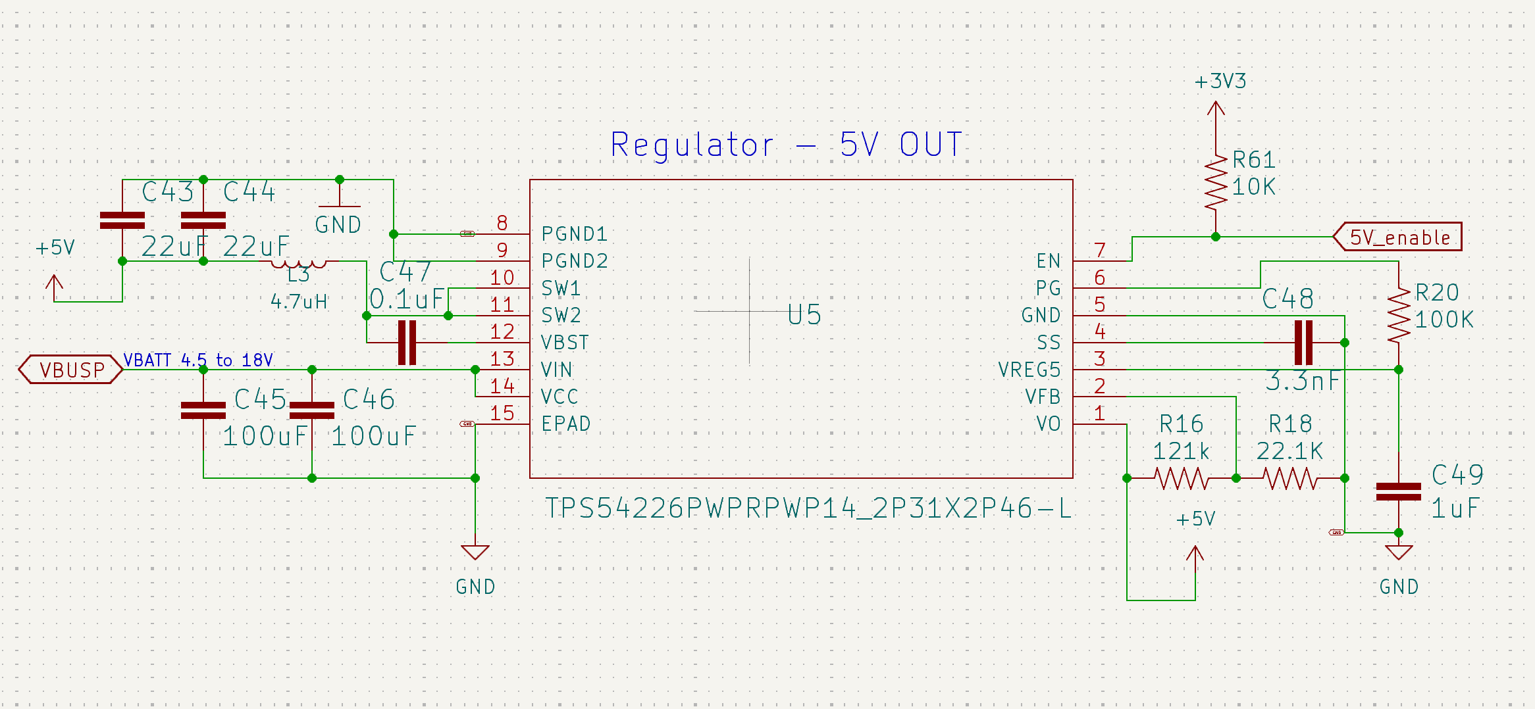
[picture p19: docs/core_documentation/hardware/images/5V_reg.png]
5V Regulator Circuit

<p align="center">Figure 4: The 5V Switching Regulator Schematic</p>

[Link to Datasheet](https://www.ti.com/lit/ds/symlink/tps54226.pdf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)

### TPS7A4501 LDO Voltage Regulator
The TPS7A4501 LDO Voltage Regulator is essential for supplying a stable 5V power to critical components like the radio on the flight controller. Although a linear regulator is more inefficient than a switching one, there are significantly lower concerns of noise on the power lines. This is important for ensuring an electrically clean enviroment for the radio to operate in. This part is borrowed from Max Holliday's PyCubed, and is believed to be slightly more radiation tolerant than other switching regulators due to there being a radiation hardened version in the part family. 

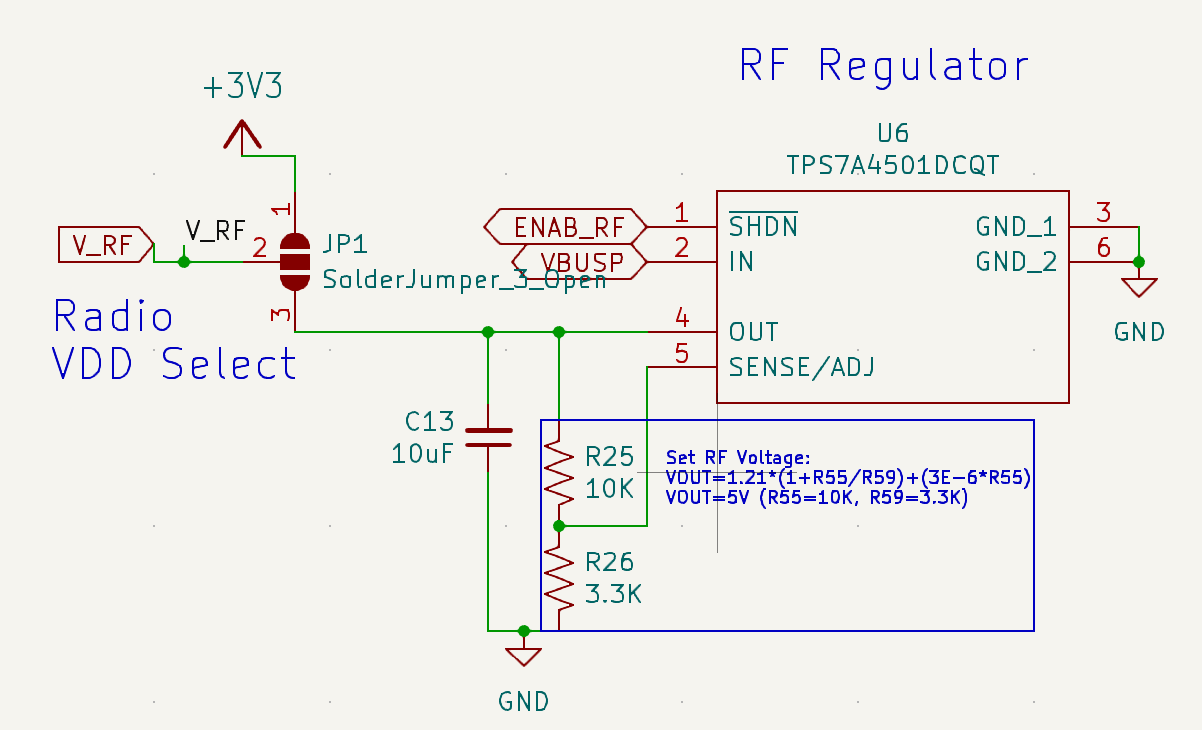
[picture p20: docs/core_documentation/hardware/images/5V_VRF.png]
5V RF Regulator Circuit

<p align="center">Figure 5: The 5V RF Regulator Schematic</p>

[Link to Datasheet](https://www.ti.com/lit/ds/symlink/tps7a45.pdf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)

### INA219 Power Monitors
These Power Monitors are crucial for real-time tracking of power input from solar cells and power consumption across the system. They provide valuable data for monitoring the health of the electrical power system and for optimizing power usage. These power monitors have extensive flight heritage across many CubeSats. 

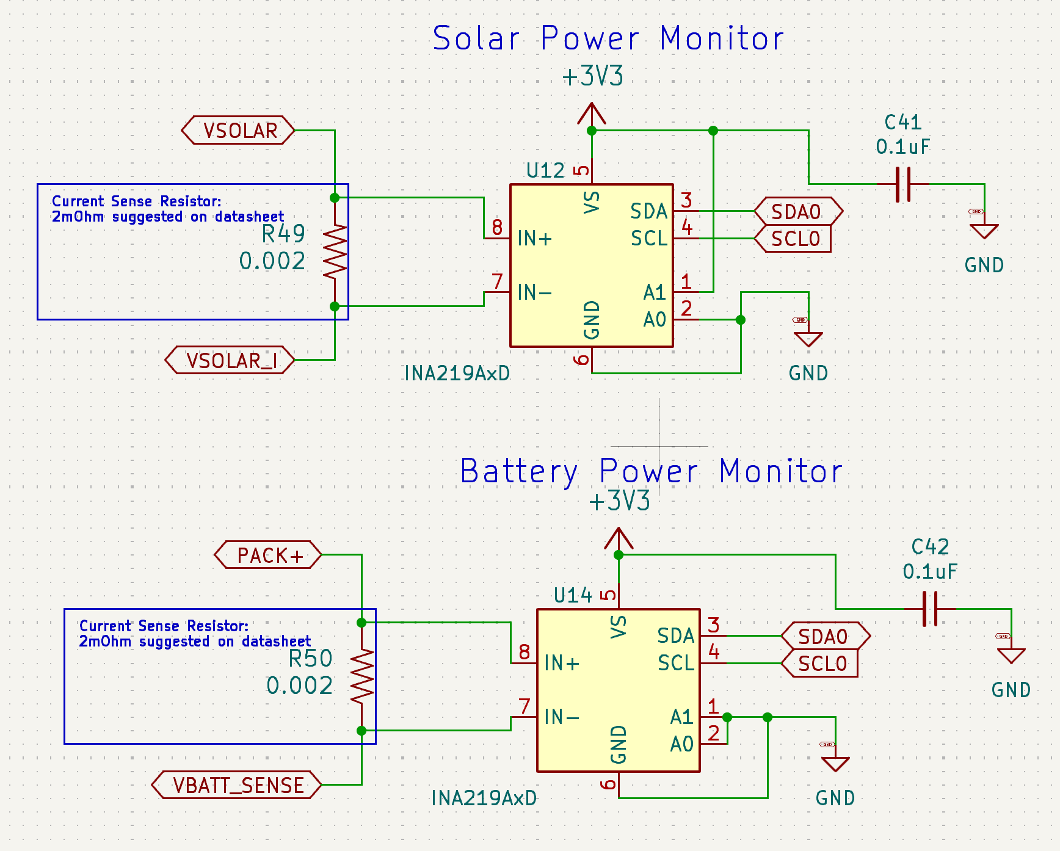
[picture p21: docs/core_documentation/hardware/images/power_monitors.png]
Power Monitor Circuits

<p align="center">Figure 6: The INA Power Monitors Schematic</p>

### PTC2075 Temperature Sensor
The PTC2075 Temperature Sensor provides ambient temperature data from inside the satellite. This information is vital for thermal management, ensuring that the satellite's components operate within their safe temperature ranges.

### R5460N208AA
The R5460N208AA plays a protective role by disconnecting the battery in cases of overcharge or overdischarge. This function is critical for battery health and safety, preventing potential damage to the power system. This part is borrowed from Max Holliday's PyCubed. 

### APAN3109 Relay
The APAN3109 Relay is used to control the flow of current to the battery heater and burn wire MOSFETs. It is an essential component for managing the deployment mechanisms and thermal systems of the satellite.

### The Burn Wire Circuit
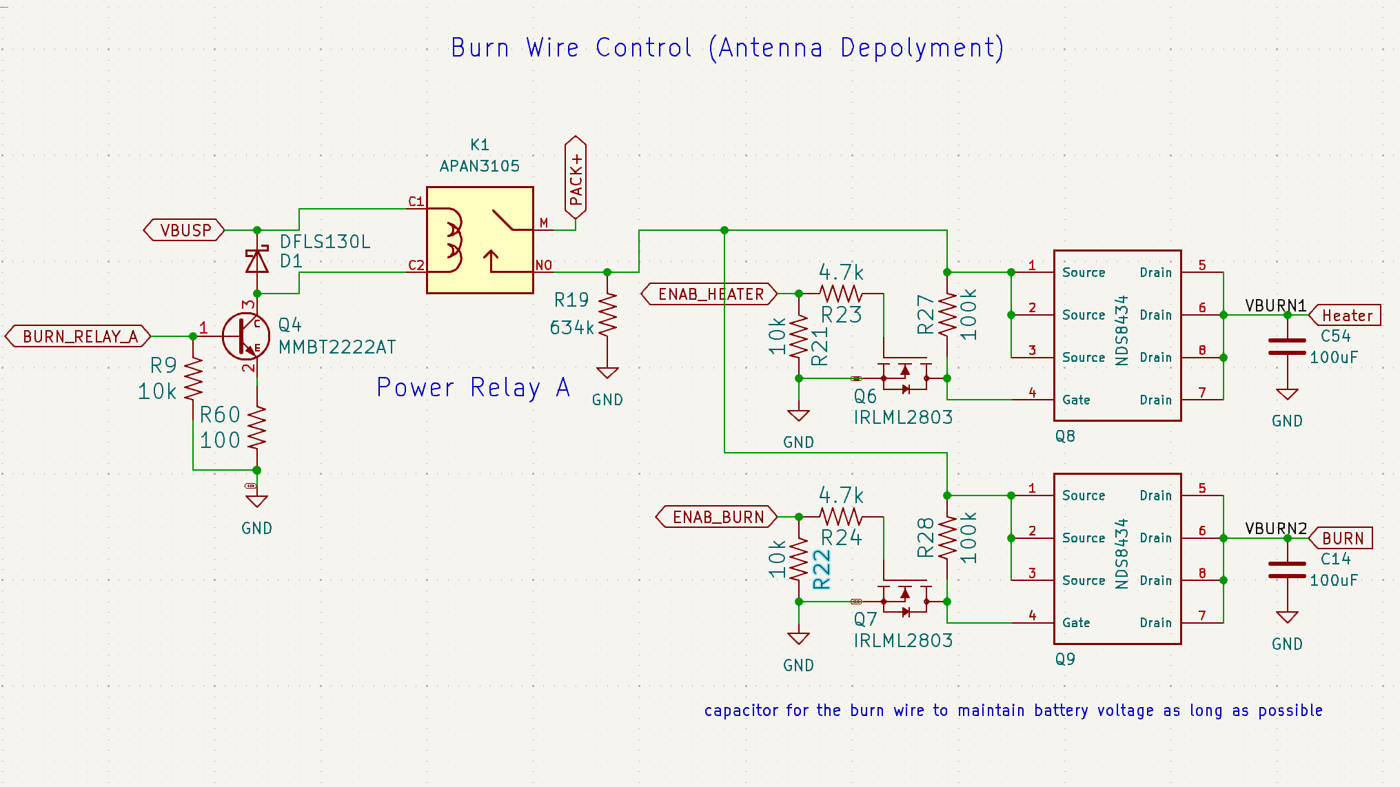
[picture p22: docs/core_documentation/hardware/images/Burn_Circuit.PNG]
Burn Wire and Battery Heater Circuits

<p align="center">Figure 6: The Burnwire and Heater Schematic</p>
In order to hold the antennas in a stowed position during launch we tie them off with a fishing line and use a nichrome wire to burn through that fishing line when it is time to deploy. This circuit is borrowed from Max Holliday's PyCubed. The NDS8434 MOSFETS are fed battery voltage to their sources when the APAN relay is closed and the voltage that they transmit through to the burnwire is modulated using a PWM signal from the uController fed into the gate. 

!!! bug "Burnwire Burn Through"

    If the power that flows through the NDS MOSFETs is too high the circuit will "burn through" and cause a short circuit that will trigger an overcurrent event any time battery voltage is introduced to the circuit. The attatched table from the ON Semi datasheet shows that although the max drain current is 6.5A, the MOSFET can only disapate between 1W and 2.5W. 

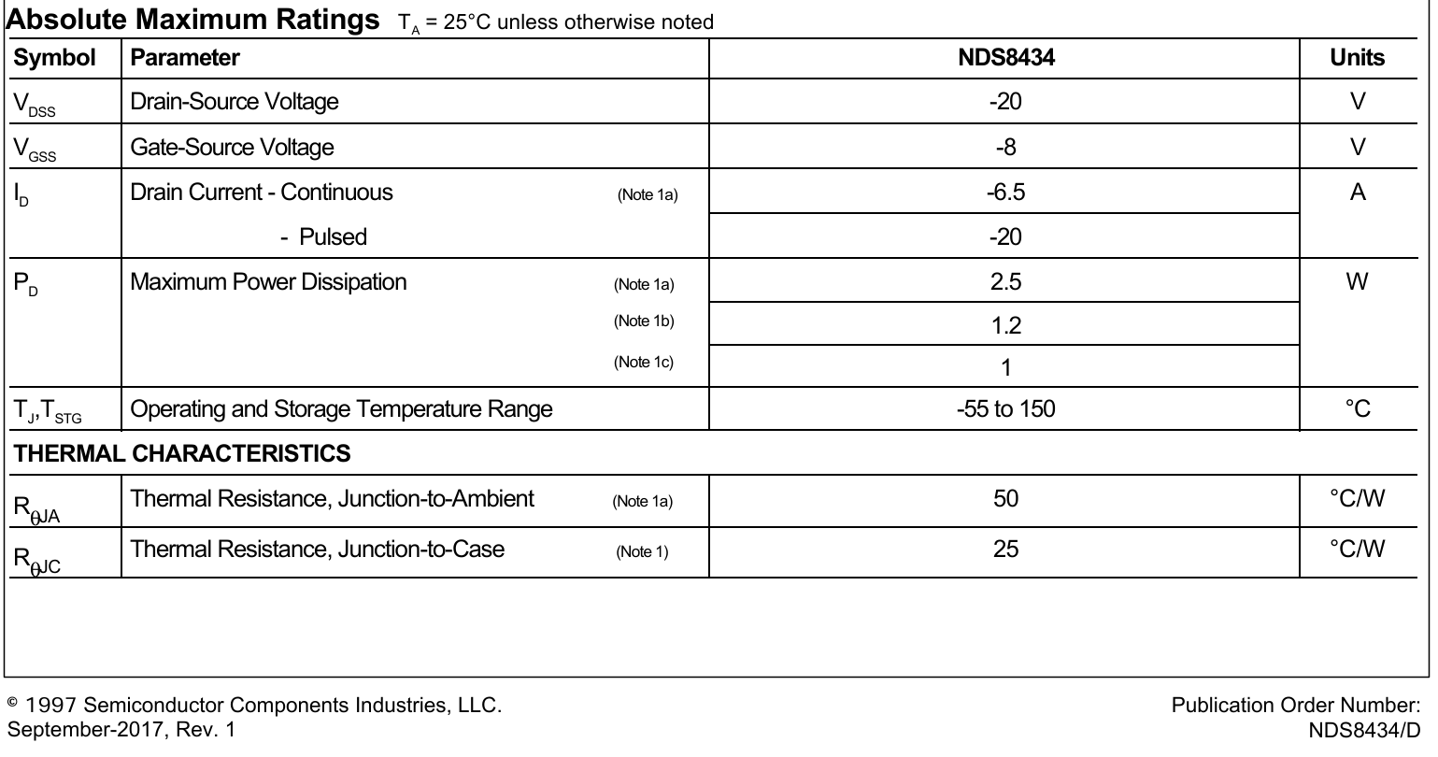
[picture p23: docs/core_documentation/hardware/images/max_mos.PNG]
MOSFET Max Ratings
    

    Right now, to consistently burn the burn wire we need to use a duty cycle of around `0.22`, which (assuming a wire resistance of ~0.3 Ohms and battery voltage of 8.0V) correlates to sending 8.53W through the circuit! Way higher than what is safe. 

    We are currently looking at changing this entire circuit out for the V4 Battery Board.

## Known Issues
1. Although the R5460N208AA is supposed to auto-release in the case of a battery protection event, it does not appear to actually do this. If you find that the satellite is not delivering power because of a battery protection event that has now been cleared, you can reset the protection circuit by "jump starting" the satellite by applying a voltage higher than the current voltage of the batteries. On-orbit these jump starts should be automatically applied by the solar charger, if they are needed. 
2. The MOSFETS in the Burn Wire and Battery Heater Circuits have much lower power carrying capacity than they should for their application. This presents a relatively high risk of "burning through" the two circuits if they get too hot, especially in vacuum. 

## Troubleshooting

*[EPS]: Electrical Power System

## Schematics
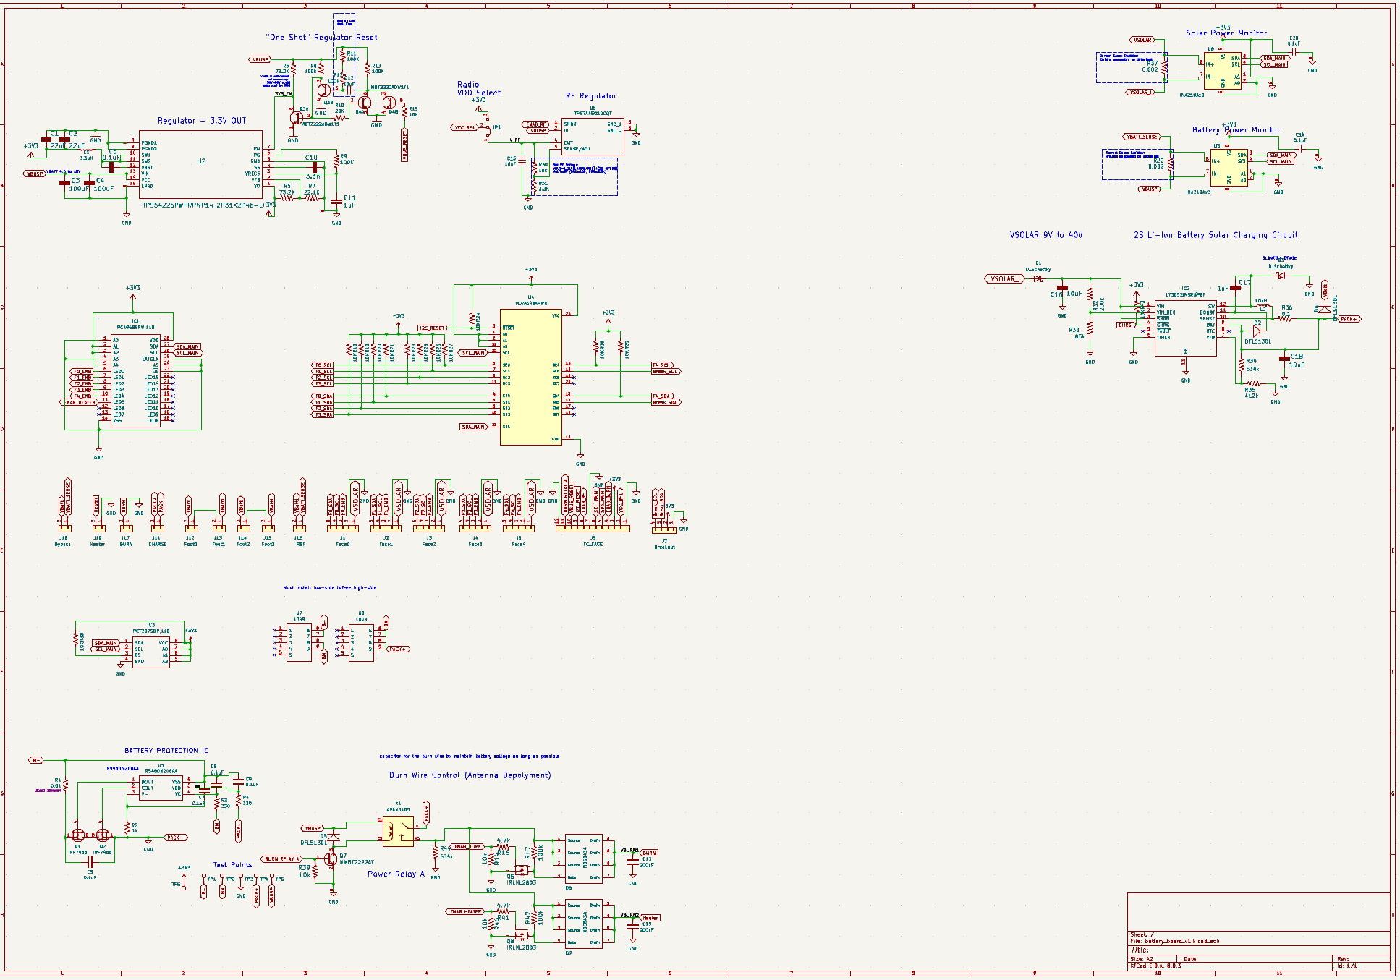
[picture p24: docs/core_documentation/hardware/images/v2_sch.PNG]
Battery Board V2 Schematic

<p align="center">The V2 Battery Board Schematic</p>

Battery Board V3 Schematic
<p align="center">The V3 Battery Board Schematic</p>

Battery Board V3a Schematic
<p align="center">The V3a Battery Board Schematic</p>

Battery Board V3a Schematic
<p align="center">The V3b Battery Board Schematic</p>

Battery Board V3a Schematic
<p align="center">The V3c Battery Board Schematic</p>

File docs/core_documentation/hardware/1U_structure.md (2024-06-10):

# Overview

<p align="center">Figure 1: The PROVES Kit Structure</p>

!!! Find the Structure on Github [Here!](https://github.com/proveskit/1U_structure)

The PROVES kit "1U" structure was designed around maximum customizability. With sixteen unique positions, several boards can fit inside to fulfill most mission requirements. The structure is laser cut, bent, and anodized 5052 Aluminum sheet metal, and is even strong enough to withstand the weight of a fully grown adult! Primary holes on the structure not joined with a bracket or hardware internally contain pressed PEM-Nuts for easy external mounting. The main structure was designed to be two separate halves that are joined together by brackets and Printed Circuit Boards.

??? note "A Structural Sidebar"
    The sheet metal structure that we now know and love as a part of the PROVES kit was designed by Gavin James after the Yearling rescope. What many people don't know though is that our sheet metal lineage actually began much earlier than that with multiple prototype structures being designed by Bronco Space Co-Founder and one time **CAD God** Ben Narita. 

    Ben and Kelsey!
    <p align="center">Figure B1: Ben and Kelsey with the Proto Structure in the El Monte Branch!</p>

    This design was really interesting, because it tried to emulate the OreSat card cage system with significantly less parts and greatly simplified manufacturing. The idea was to use a slotted sheet metal sandwich structure to create a clinching force when set screws were threaded in to deform an inner layer. It could have been pretty cool! We never followed through with trying to make it work long term though, since the much simpler half-u style structure won out in the long run. 

    Protostructure Close Up
    <p align="center">Figure B2: A Close Up of the Proto Structure</p>
   
## The Primary Structure
The primary structure of the satellite is usually considered the parts of the physical structure that will carry load during the launch environment and define the first resonant mode. Within the PROVES Kit we have two “Half U’s” that are joined by two “L-Brackets” connecting the top and bottom flanges of the half U’s”. The Half-U’s have a series of holes that run up and down the structure to provide spots for mounting “Card Brackets” which carry any component that needs to be held inside of the CubeSat. Additionally, there are eight “Foot Assemblies” that serve the dual purpose of providing a uniform satellite to satellite interface (when multiple 1U’s are stacked with each other) and containing the inhibit switches that keep the satellite turned off while it is inside the deployer. 

<p align="center">Figure 2: The Raw PROVES Kit Structure Components</p>

!!! warning 
    When selecting fasteners do not use Zinc Plated. Although the risk is low, use of Zinc Plated Fasteners for flight can cause issues with your launch provider. See this [NASA site](https://nepp.nasa.gov/whisker/reference/tech_papers/Brusse2003-Zinc-Whisker-Awareness.pdf) for more details. 

### Half U's
- **Material:** 1.6mm Thickness 5052 Formable Aluminum Sheet Metal 
- **Recommended Fasteners:** CLS-M2.5-2, Self-Clinching Nuts | 18-8 Stainless Steel M2.5x5mm T8 Torx Panhead

<p align="center">Figure 3: The Half U's</p>

### Brackets 
- **Material:** 1.6mm Thickness 5052 Formable Aluminum Sheet Metal 
- **Recommended Fasteners:** CLS-M2.5-2, Self-Clinching Nuts | 18-8 Stainless Steel M2.5x5mm T8 Torx Panhead

### Feet Assemblies 
- **Material:** PA-12 Nylon made in MJF or SLS 3D Printing Process
- **Recommended Fasteners:** 

The structure also maintains mounting holes for feet on each structure half, and each 3D printed foot can house switches for inhibiting the satellite. When the satellite is in the deployment pod on its way to space, it needs to remain off until it has been deployed. While the satellite is in the pod, its feet are covered, and thus embedded switches can be depressed to inhibit the satellite. After the satellite is deployed, with nothing depressing the switches, the satellite can spring to life. 


<p align="center">Figure 4: The Current Footswitch Design</p>

There doesn’t seem to be a coined term for the method we use for the inhibit switches, so we just call them the “BroncoSat Style” because we first used it on BroncoSat-1. This style of inhibit features a mechanical limit switch that is wired in the Normally Closed (NO) form, with an M2 screw is used as a plunger that travels through the foot and clicks the circuit into the Open state when the plunger is depressed. We take advantage of the built in leaf spring on the limit switch to reject the plunger when there is nothing holding it down, and a nut is present to retain the plunger within the satellite. 

The primary reason that we opted to 3D print the feet rather than machine them is to save a radical amount of cost for the complex geometry needed. For anecdotal comparison, each of the 3D printed feet costs exactly \$1 to manufacture whereas one of our CNC feet would cost about \$54. 

There also exists an older part number that uses SDS005R microswitches to detect deployment. We refer to this as “BIRDS Style” because it is used by the Japanese BIRDS Open Source CubeSat Bus. The reason these switches are no longer used is that they are an incredible pain to assemble into the satellite and sometimes can be burned through by the burn wire circuit. These older feet can be used if you must absolutely optimize internal volume or need a part that can be CNC machined when the extra strength is needed or a launch provider will not budge on the requirement that all the touch points for the structure must be made of metal. 

## Peripheral Hardware
A Remove Before Flight ("RBF") switch and pin can also be added to the satellites top cap PCB for inhibitting the satellite as it is transported and placed in the deployment pod. The bracket that is mounted to the top cap PCB can house the switch and the top cap PCB features a hole for dropping a pin into place to depress the RBF switch.


<p align="center">Figure 5: Taking the Jig for a Spin</p>

The Jig is also a valuable piece of hardware for squaring up the structure during assembly. We recommend 3D printing one on a printer known to have good dimensional accuracy and using it throughout the build and intergration process.

## Expansion & Varients
The PROVES kit can be expanded to stack structures to meet larger satellite requirements (such as a "3u"). Special feet have been designed for this very concept to help join the structures together. This design implementation is completely experimental and has not ever been vibration tested or qualified for space. With the PROVES kit design being open-source, the concept could be tested and experimented with by anyone to further improve the community using the designs.

For fun, Adam Elsharhawy has also been working on a carbon fiber varient of the structure! 


<p align="center">Figure 6: Carbon Fiber!</p>

## Qualified for space
An Earlier version of the kit was vibration tested for 20 g's RMS. As stated earlier, the kit's structure can withstand the weight of an adult. The kit has been put through intense thermal cycling and has also survived. After two mission successes, the PROVES kit structure can easily qualify for space.

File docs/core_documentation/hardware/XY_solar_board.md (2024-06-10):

# Overview
The PROVES kit XY Solar Boards...


<p align="center">Figure 1: A Render of the Pleiades Five XY Solar Board</p>
## Getting Started

!!! Find the Structure on Github [Here!](https://github.com/proveskit/solar_boards)

## Utilized Parts
Each XY solar panel implements the following elements:

### (6) AnySolar KXOB101K08TF Solar Cells in a 2s3p configuration 
These are silicon solar cells from the Korean company AnySolar. They seem to be of a similar makeup to those employed by calculators. There is an EVA film that protects the cells and is fairly resilient. 

One of the big things that the really expensive triple junction cells bring to the table is guarantee of performance in the space environment over a 25 year mission life. We have no idea how well these AnySolar cells would do after years of being in space, but the Stanford team has validated at least 3 solid months of lifetime out of them with no noticeable degradation. 

### Microchip MCP9808T-E/MC I2C Temperature Sensor 
This is a temperature sensor. Not much else to say about it. 

### TI DRV2605LDGSR I2C Haptic Motor Drivers 
These low current motor drivers are used to energize the magnetorquer coils inside the PCB. Because the solar boards are a 4-layer PCB, we were able to stick two artisinally hand drawn coils that are connectd to these motor drivers. The haptic motor drivers push very little current through the coils, but it is still enough to create enough of a magnetic field for detumbling! 

### Vishay VEML7700-TT Ambient Light Sensors 
The ambient light sensor returns a luminance value proportional to the angle of incidence of the sun. It tracks roughly a bell curve. 

### Fun Blue LED!
A great indicator that everything is powered up! 

### 5-pin Molex 1.5mm Pitch Picolock
This positivly locking conenctor carries VSolar, 3.3V Power, Ground, and I2C connections for all the face sensors. 

## Design Rationale
The goal for the these XY solar panels is to create a solar panel board that can work on any XY face of the satellite without modification. This modularity allows us to reduce the number of unique parts, simplifying integration and testing while also reducing cost in manufacturing. 

### Use of Silicon Solar Cells vs Gallium Arsenide
Most traditional space missions fly using Gallium Arsenide (also referred to as GaAs or Triple Junction) cells due to their very high efficiency. By our reckoning, virtually the entire Triple Junction solar cell industry serves space applications as the extremely high cost of these cells prohibits their use for any terrestrial applications. 

Today it is believed that silicon solar cells are actually the most common solar cell chemistry flown in LEO (pretty much all of them on Starlink satellites) due to their very robust supply chain and radiacally lower cost. 

## Known Issues
There are no known issues with the solar panels. Amanda kind of hit it out of the park on the first try! 

## Troubleshooting

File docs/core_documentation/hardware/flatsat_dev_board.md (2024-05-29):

# The FlatSat Dev Board 
We decided that it would be a good idea to create a single board that has all of the core electrical compoenents of the PROVES Kit for use in the classroom, on the lab bench, and in field testing! This board would be pretty difficult to fit in a 100mm x 100mm envelope, so it is not CubeSat form factor, but it still captures all of the core CubeSat functionalities! 


<p align="center">Figure 1: The FlatSat Block Diagram</p>

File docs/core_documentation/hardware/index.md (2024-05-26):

# Hardware Overview
The PROVES kit hardware is completely open source and all design files are viewable on the [GitHub](www.github.com/proveskit).
## Overview
The Hardware is split into the respective components of the structure, brackets, PCBs, and other hardware recommendations. 

The PCBs currently implemented internally is the battery board. Outer facing boards currently being supported is the Flight Controller (FC) board, XY Solar boards, and Z- board. The Flight Controller board is implemented on the top cap of the satellite also known as the Z+ Face while the Z- Solar board is the bottom cap of the satellite.

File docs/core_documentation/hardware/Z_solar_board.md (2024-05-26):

# Overview
The PROVES kit Z- Solar Boards...
## Getting Started

## Utilized Parts
The Z- solar panel implements the following elements: 

- **(6) AnySolar KXOB101K08TF** Solar Cells in a 2s3p configuration 
- **Microchip MCP9808T-E/MC** I2C Temperature Sensor 
- **TI DRV2605LDGSR** I2C Haptic Motor Drivers 
- **Vishay VEML7700-TT** Ambient Light Sensors 
- **Fun Blue LED!**
- **5-pin Molex 1.5mm Pitch Picolock** for VSolar, 3.3V Power, and I2C connections

## Known Issues

## Troubleshooting

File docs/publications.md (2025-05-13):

# Notable Publications

## Blake and Nate's Lightning Talk at PyTexas 2025
This was presented in person at PyTexas 2025 by software contributors Blake and Nate.

<iframe width="560" height="315" src="https://www.youtube.com/embed/EvwtBFz5iME?si=QcBYWP5j-dJx3svy&amp;start=433" title="YouTube video player" frameborder="0" allow="accelerometer; autoplay; clipboard-write; encrypted-media; gyroscope; picture-in-picture; web-share" referrerpolicy="strict-origin-when-cross-origin" allowfullscreen></iframe>

## BIRDS Open Source Webinar: The Any% Method: A Lessons Learned on Designing and Executing LeanSat Missions Quickly and Affordably 
This was presented virtually during the Feb 2024 BIRDS Open Source Webinar. 



## IWLS 2023: Lessons Learned from 4 Back to Back Satellites on 4 SpaceX Transporter Launches
This was presented at the International Workshop on Lean Satellite in Tokyo in December 2023. It is currently the most up to date record of Bronco Space satellites. 



## CDW 2023: A Low-Cost Educational CubeSat Kit
This was presented at the CDW 2023. It is currently the most up to date record of the Day 1 Session 3 by Beck.



## CDW 2023: CubeSats are the Stroads of the Space Industry
This was presented at the CDW 2023. It is currently the most up to date record of the Day 1 Session 3 by Pham.



## CDW 2023: PROVES Electionics
This was presented at the CDW 2023. It is currently the most up to date record of the Day 3 Session 8 by Ewing.



## SmallSat 2022 The Pleiades CubeSat Cluster: Enabling Open Architectures and Satellite Collaboration
This poster was presented at both the 2021 ASGSR Meeting and the 2022 SmallSat Conference! It laid some of the ground work for why we believed more open source CubeSat activity was needed to build a stronger space community. 



## SmallSat 2020 QUIC: The Quickly Universally Integrated CubeSat
This was the very first poster referencing our idea of creating a novel CubeSat bus! 

<iframe src="https://digitalcommons.usu.edu/cgi/viewcontent.cgi?article=4662&context=smallsat" style="width:100%; height:500px;" frameborder="0"></iframe>

<!-- Repeat the pattern for more publications -->

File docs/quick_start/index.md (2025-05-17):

# A CubeSat Quick Start Guide

<div class="grid cards" markdown>

-   :material-cube-send:{ .lg .middle } __CubeSat Context__

    ---

    Whether you're a new or veteran developer, it is always a good idea to stay up to date with the state of CubeSats. 

    [:octicons-arrow-right-24: CubeSat Fundementals](https://docs.proveskit.space/en/latest/quick_start/cubesat_fundamentals/)

-   :material-clock-fast:{ .lg .middle } __Set up in 5 minutes__

    ---

    It is quick and easy to get started interacting with the PROVES Kit! Check out the quick start guide here.

    [:octicons-arrow-right-24: Getting started](https://docs.proveskit.space/en/latest/quick_start/proves_quick_start/)

-   :material-format-font:{ .lg .middle } __Contribute to the Project!__

    ---

    Open source project rely on users like you contributing to the source! If you have some ideas about how things can be better join us!

    [:octicons-arrow-right-24: Becoming a Contributor](https://docs.proveskit.space/en/latest/quick_start/becoming_contributor/)

-   :material-scale-balance:{ .lg .middle } __Simple, Open, and Accessible__

    ---

    We're dedicated to creating as much open access to space as possible! Check out our reasons for why here.

    [:octicons-arrow-right-24: Philosophy](https://docs.proveskit.space/en/latest/design_philosophy/)

</div>

# The PROVES Kit Version Explainer
Updated May 17, 2025

## V1 PROVES Kit: Released in 2023
The was the initial version of the PROVES Kit based on the Yearling generation of satellites. Support for these versions is only available to existing users and they are not recommended for new missions.

Known Users:
- Northeastern Project Horizon
- UNLV RebelSat
- Montogomery High School 
- St. Louis University
- Harvard SEDS (custom version?)
- Arizona State University COCONUT (created derivative architecture - the 6Py perhaps?)

Board Versions:
- Flight Controller Board V3
- XY Solar Panel Board V1
- Z- Solar Panel Board V1
- Battery Board V2a

Known Major Issues:
- Increased suspectability to thermal shutdown and radiation upsets due to the V3 Flight Controller Board

## V1.5 PROVES Kit: Created in 2024
This version of the PROVES kit is a combination of significant improvements made in V4 flight controller boards along with a modified legacy battery board configuration (V2b). The VT InspireFly team will be flying this version of the kit on their Content Cube mission (already delivered for flight to the ISS!) in 2025 and we eagerly await their inflight results. This was also the first version to include a significantly improved radiation tolerant watchdog circuit. 

Known Users:
- Virginia Tech InspireFly (Launching to the ISS in 2025!)

Board Versions:
- Flight Controller Board V4c InspireFly Special
- XY Solar Panel Board V1
- Z- Solar Panel Board V1
- Battery Board V2b
- Custom unreleased antenna board

Known Major Issues:
- Lack of stable and officially supported software

## V2 PROVES Kit: Released in 2024
V2 of the PROVES Kit was developed for the Irvington High School Girls in STEM team to fly on the Orpheus satellite. This version of the kit was successfully launched in December 2024 on the SpaceX Bandwagon - 2 mission. On orbit performance was as expected aside from a major software error that caused the radio transmit power to be stuck at 100mW instead of 1W EIRP. As a result, the camera module included in this version of the kit could not be verified on orbit due to link budget issues. 

Known Users:
- Irvington High School (Launched on Pleiades - Orpheus satellite!) 
- Texas State Space Lab

Board Versions:
- Flight Controller Board V4c Express
- XY Solar Panel Board V1
- Z- Solar Panel Board Combi V1
- Mux Driver Board V1
- Camera Driver Board V1
- Battery Board V3c
- Antenna Board V1

Known Major Issues:
- Lack of stable and officially supported software
- Major software bug severely limiting radio transmit power (fix available)
- Power budget is extremely poor due to all of the additional components and no proper load switching circuits

## Upcoming V3 PROVES Kit: Planned Release No Later Than August 2025
Known Developers:
- Bronco Space Lab (Lead Developer)
- Texas State Space Lab (Primary Software Development Team)
- UCSC SlugSat
- Northeastern Project Horizon
- Columbia Space Initiative 
- NASA JPL Small Scale Flight Software Team (possesses Flight Controller Boards for evaluation - development of an F Prime PROVES deployment is planned for 2025)

Board Versions:
- Flight Controller Board V5x
- XY Solar Panel Board V2
- Z- Solar Panel Board V2a
- Battery Pack V2
- Antenna Board V2

Major Improvements
- Upgrade to RP2350 Microcontroller
- Additional S-Band Radio 
- Proper load switching circuitry to manage the power used by peripherals
- Dramatically overhauled software and developer tools

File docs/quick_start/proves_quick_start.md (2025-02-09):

# So You Have a PROVES Kit!
The Yearling Fleet!
<p align="center">The Pleiades - Yearling Fleet</p>

We are assuming that you have received a fully assembled PROVES Kit to get started. If you only have the indivudual components please refer to the the assembly guide to get things together or the individual checkout procedures for individual components. 

## Prerequisites 

Before we crack into using our PROVES Kit it is important to learn, acquire, or install a few useful tools. 

#### Required Items
In order to interact with the hardware, we will need to install some software that will give us the ability to view and change the code from a serial terminal, download the latest code from the the Github, and edit the code if we desire. Make sure all of these tools are installed on your computer using the links below before proceeding! 

??? success "A Serial Terminal Software"
    We need some way to read the output of the satellite on a serial port and ideally a way to also type serial commands back during debugging.Any software that is capable of opening a serial port will do (even the built in terminal on Linux and MacOS will work!), but we recommend installing something like Tabby for a better user experience.  

    Tabby Terminal

    <p align="center">Figure 1: An example Tabby Landing Page</p>

    Learn more about Tabby [here](https://tabby.sh). 

??? success "A Code Editor"
    If you're a Linux lunatic you could view and edit all of your code on the command line using Vim or something, but our recommendation for a good user experience is something like Visual Studio Code!   

    VS Code

    <p align="center">Figure 2: An example VS Code Page Page</p>

    Learn more about VS Code [here](https://code.visualstudio.com). 

!!! sucess "A Working Knowledge of CircuitPython" 
    It is highly recommended that you get a fundemental understanding of how CircuitPython works before working with the PROVES Kit. CircuitPython is the easiest way to interface with and run tests on the hardware. 

    Check out the Adafruit CiruitPython [here](https://learn.adafruit.com/welcome-to-circuitpython/overview).

Note that these recommendations are for Windows and MacOS users. We presume that if you’re joining us from Linux you probably have your own way of doing all of this. 

#### Recommended Items

???+ info "Github Desktop"
    Another one where if you are a power user you probably don't need this, but GitHub Desktop puts a really nice GUI in front of the Git experience. We use this to pull and push all of the code and design files from the GitHub repos.
    
    Learn more about GitHub Desktop [here](https://desktop.github.com).

There are a few hardware tools that are helpful when working with the satellite as well. A micro USB cable is essential, to connect to the satellite and pull data from it. The multimeter is useful for measuring the voltages across various parts of the kit to verify functionality. An SDR (Software Defined Radio) is completely optional, but very useful for verifying that the radio is working and it is also cool to listen into the airwaves around you. 

Hardware:

- Multimeter 
- Micro USB Cable
- SDR (Optional) 

## Initial Checkouts 

Assuming that you have a fully assembled PROVES Kit in front of you, we will go through a quick tour of the major features of the kit!

### Function Check
Currently there is no dedicated function check script. The best way to validate if all of satellite's subsystems are online is to use the built in state of health functionality in the ```pysquared.py``` class. To do this, take the following steps: 

1. Connect to the satellite via the micro usb cable. You should see a USB drive pop up if you're using the CircuitPython firmware.
2. Open a serial connection using Tabby. 
3. Use the keyboard shortcut ++ctrl+c++ to interupt any currently running code and follow the instructions that pop up to enter the REPL
4. Once you enter the REPL, a `satellite` object will be imported and called `c` to give access to the core satellite functionalities.
    
    !!! info "What does this command do?"
        This line of code instantiates the ```cubesat``` class within ```pysquared.py``` and names it an object ```c```. 
        
        This gives us access to all of the core functionalities of the the satellite within a single object. We borrowed this design pattern from Max Holliday's PyCubed software implementation, so alot of the functionalities cross over. 

5. Call the ```c.hardware``` dictionary to determine if all of the satellite functionalities are ```true```. 

### Radio Check
With an active instance of the ```cubesat``` class we can quickly send some packets to validate that the radio is operational. Make sure to check the properties in the ```self.radio_cfg``` dictionary before proceeding: 

```py 
    #Default Configuration 
    self.radio_cfg = {
        'id':   0xfb,   # The ID of the sender
        'gs':   0xfa,   # The ID of the receiver
        'freq': 437.4,  # Transmit frequency
        'sf':   8,      # LoRa Spreading Factor
        'bw':   125,    # Transmit bandwidth
        'cr':   8,      # LoRa Coding Rate
        'pwr':  23,     # Transmit power
        'st' :  80000   
    }
```

1. First, configure something to listen in and monitor the radio waves:

    ??? info "Using an SDR"
        If you have a SDR hooked up, tune into to frequency that you're transmitting on and watch the waterfall. 

    ??? info "Using another HopeRF Radio Module"
        If you have a second PROVES Kit, a Flight Controller Dev Board, or a standalone RFM98PW you can use that to monitor for transmissions as well. Make sure that the ```'id'``` and ```'gs'``` parameters on the receiving node are the opposite of what they are on the sending node. 

        Once you're ready to start receiving you can setup a receiving loop with the following coding pattern: 

        ```py
        from pysquared import cubesat as c
        import time

        while True:
            time.sleep(1)
            print(c.radio1.receive())
        ```

        This code will print either ```none``` when there is no received message or a whatever message has come over the airwaves if there is a valid packet. It can either be implemented as its own script and called or you're a pro gamer you can type it line by line into the REPL. 

        If you are using a stand alone RFM98PW with a dev board you'll have to go through setting up the pins and radio object for the specific microcontroller you're pairing it with. We recommend referring to the [Adafruit RFM9x documentation](https://learn.adafruit.com/adafruit-rfm69hcw-and-rfm96-rfm95-rfm98-lora-packet-padio-breakouts/circuitpython-for-rfm9x-lora) for how to do that. 

        This is the most basic pattern for receiving and demodulating messages. For more advanced (and useful) test patterns please refer to our dedicated page on [RFM9x Radio Usage](https://docs.proveskit.space/en/latest/core_documentation/software/rfm_radio_usage/).

2. You can now send a packet using a command such as: 
    ```c.radio1.send("Hello World!")```

    !!! warning
        If your PROVES Kit is equipped with the RFM98PW (the 433 Mhz Band radio) use caution when calling ```c.radio1.send()``` directly, as it bypasses the ```c.is_licensed``` parameter that will usually stop you from violating FCC regulations unless you've verified you have a valid license to operate the radio.  

3. Check if the message comes through! Each call of ```c.radio1.send()``` should return ```True``` if the radio accepts the string and sends it out sucessfully. You should also see the following things on whatever receiving device you're using as well: 

    ??? info "Using an SDR"
        You should see a blip on the SDR shortly after using the ```send``` command. What that blip looks like will be different, depending on which modulation you are using: 

        - LoRa Mode 
        ![Example LoRa Messages](images/LoRa_Look.png)
        <p align="center">Example LoRa Messages</p>

        - FSK Mode

    ??? info "Using another HopeRF Radio Module"
        If you are receiving from a HopeRF module your serial terminal should look someting like this: 

!!! tip 
    There is now also a niffty ```radio_test.py``` script that helps to automate this process! Find it [here](https://github.com/proveskit/test_scripts).

### Acquiring Face Data

Unless you have already implemented a payload into the PROVES Kit, most of the data you'll be interested in is the data reported by the satellite's faces. In order to poll this: 

1. Connect either to your top cap FC board or the EPS Board running Circuit Python and enter the REPL. 
2. Set up the ```cubesat``` object. 
    ```py 
    from pysquared import cubesat as c
    ```
3. Import the functions library. 
    ```py 
    import functions
    ```  
4. Instantiate a functions object and pass the ```c``` object to it. 
    ```py 
    f = functions.functions(c)
    ```
5. Call ```f.all_face_data()```. You should expect an output like this: 
Example Face Data
<p align="center">Example Face Data Output</p>

### Conducting a Range Test
One of the number one things that keeps us up at night with the satellite is whether or not we will actually hear back from it after sending it off on its journey in outer space. As a result, a fundemental test to do for every build is a verification of the performance of the radio at long range. We will have a seperate page forthcoming that goes into detail about the reasons and methedology behind this test, but we will quickly reference some of the key steps here: 

1. Position a sending and receiving node some distance away from each other. We recommend at least 1km of seperation and a clear line of sight between the two nodes. 
2. Use the ```radio_test.py``` function on both devices to send and receive pings! Find that script [here](https://github.com/proveskit/test_scripts)
3. Record the RSSI (Received Signal Strength Indicator) values and see what your link margin is looking like. 

## Changing the Code
Inevitably you'll want to change the code out on one of your boards. By default we recommend the CircuitPython implementation be loaded on the boards for ground testing, but this should be swapped out for more resiliant code before flight. 

### Flashing Firmware 
Changing out the firmware on the microcontrollers is how we can switch between using CircuitPython or C/C++ binaries for our flight software. Ocasionally the dev team will also push an update directly to firmware, but this usally only happens when we have a hardware update, want to use a newer compiler, or have discovered a critical bug. 

1. Connect to the board using USB 
2. Locate the **RESET** and **BOOTSELECT** buttons on the board in question: 

    ??? info "Flight Controller Board" 
        Description of where the Boot Select and Reset are
        <p align="center">Internal FC Board Button Locations</p>

    ??? info "Battery Board"
        Description of where the Boot Select and Reset are
        <p align="center">Battery Board Button Locations</p>

3. While holding the **BOOTSELECT** button, tap the **RESET** button 
4. The board will now reboot into bootloader mode 
5. Once in bootloader mode you can drag and drop a new ```.uf2``` file in as needed. 

The latest version of the CiruitPython firmware can be found in the dedicated repo for each board. As an exmaple, check out the flight controller board firmware [here](https://github.com/proveskit/flight_controller_board/tree/main/Firmware).

??? note "Can't Reach the Buttons?" 
    If you're currently using binaries, and want to switch to CircuitPython or update the firmware, sorry but you'll have to disassemble to access the buttons for a swap. 

    If you're currently using CircuitPython you're in luck! There are some REPL commands that can come to the rescue. Just type the following into a fresh terminal: 
    ```py
    import microcontroller
    microcontroller.on_next_reset(microcontroller.RunMode.UF2)
    microcontroller.reset()
    ```

### Updating CircuitPython Software 
Updating the CircuitPythong software is remarkably easy and painless, which is part of why we love using it so much in the lab and in the classroom!

1. Get the code you want to update from the GitHub or your local machine. 
2. Connect to the board you want to update via USB. You should see a removable drive pop up when it is plugged into your computer. 
3. Drag and drop the new code over top of the old code! 

*[REPL]: Read Print Evaluate Loop
*[SDR]: Software Defined Radio

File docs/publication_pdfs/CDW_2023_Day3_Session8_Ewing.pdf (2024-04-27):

# PROVES


# Electronics

## Amanda Ewing and Nicole Maggard

## Senior Engineering Students in Bronco Space at Cal Poly Pomona

## Unlocking Space with Modularity and Affordability

# Agenda

# - PROVES • Challenges • Background • Yearling • Xmera (Chimera) • Subsystems • Impact


# PROVES: Pleaides Rapid Orbital Verification Experimental System

# Rapid

# Verification

# Experimental

# Challenges


- Space is really hard o | We failed twice before success • Space is expensive o | Intention is to get it right the first time o | BroncoSat-1 cost about $48k in just

## components

- Stop reinventing the wheel o | Offer up a standard • Difficult to scale designs up o | Make design expandable


# Background

## - Two architecture paths

## - PC/104 mounting hole pattern

### - Artemis CubeSat Kit

### - PyCubed

## - Backplane

## - Which one to use?

## - Yearling satellites used PC/104

## - Xmera satellite will use backplane


Credit: Max Holliday, REX Lab, Stanford

Credit: Hawaii Space Flight Laboratory

# Yearling


### Used PC/104 -mounting hole pattern

- Launched January 3rd,
2023
- Failed to deploy

### Yearling

-1

### used the PyCubed

- Launched April 14th,
2023
- First received packet April 15th, 2023

### Yearling

-2

### used the 3PySquared


# Design

Drivers • Inexpensive o | | | | Use of off-the
| | | | -shelf components

### - Increase accessibility

- Fast Design Turnaround o | Internal organization goals o | Readily available hardware • Open Source o | Access software and hardware designs o | End user can easily adjust standards to

### their needs - Tutorials in the pipeline


# PC/104 Key

Features • | Held in place by brackets or standoffs • | Can connect cards with stackable connectors

### or cables

### - Boards can function independently of each other

- | Not limited to backplane connections o | Physical Spacing o | Electrical interface • | Can densely stack electronics

# Xmera


## Implements backplane architecture

## Uses similar components as Yearling

## Work

-in

## -progress

## Has potential to be expanded

# Design


Drivers • | | | | | | | | Affordable & Open -Source
- | Cards slot directly with backplane o | Minimal cabling o | Easier access to internal cards o | Easier to troubleshoot o | Adds structural support • | Scalability • | Modular Subsystems o | Easily customizable


# Backplane Key Features

- Cards held in place by brackets and electrical interface
- Standardized spacing
- Larger cards skip slots
- Mix and Match cards for mission needs
- Ex: Multiple EPS cards can be easily stacked for additional power budget
- Ex: Extra flight computer for redundancy
- Backplane expandable for larger satellites
- No wiring
- Possible standardized interface
connector | 11

# Subsystems

Solar; Software; Payload

Command and Data Handling (C&DH)

Attitude Determination Control System
(ADCS)

Electrical Power System (EPS)

# Command and Data Handling


Similarities:

- Utilizes a HopeRF RFM9x module
- LoRa modulation
- 430MHz range
- Utilizes an RP2040
o | Flight heritage
o | Extremely inexpensive

PC/104:

- Integrated attitude control

Backplane:

- Designed as top cap but could be slotted internally

From Yearling-2
(PC/104)


From Xmera (BP)


# Attitude Determination Control System

Similarities:
- Contains accelerometers, gyroscopes, and magnetometers
PC/104:
- Integrated on Command and Data Handling board Backplane:
- 40 pin breakout
- Could interface with Raspberry Pi zero
- Could interface with custom compute module
- Embedded magnetorquer coil
- Contains motor drivers
- Interfaces with magnetorquer coils, reaction wheels, or other attitude control device through the


Backplane | 14

Both From Xmera (BP)

# Electrical


# Power System

Similarities:

- Utilizes LT3652 to charge batteries from solar power
- Maintains all controls for battery heater
- Contains inputs for inhibit switches

PC/104:

- Cabled directly to C&DH board, solar boards and switches individually

Backplane:

- Utilize an RP2040 to track power
consumption, and make power-based
decisions for the satellite | 15

From Yearling-2
(PC/104)

From Xmera (BP)

# Solar


## Similarities: • Off-the-shelf components

## and sensors

### - Embedded magnetorquer coil

## PC/104: • Each face cabled to Battery

## Board

## - Integrated motor drivers

## Backplane: • Fully modular subsystem

## with single backplane

interface | 16

From Yearling

-2
(PC/104)

From Xmera (BP)

# Flight Software


### - Utilizes CircuitPython

### - Beginner Friendly

### - Maintained by Adafruit

### - Teaches Object Oriented Programming

### - Easy to debug

# Payload

# - Unlimited Variations

# - Unlimited Expansion

# - Unlimited Extrapolation

# - Limited only by Creativity


Cosmic Watch

# Impact


# - Great educational tool - Opportunity for industry progress - Space for All

# - Be inspired - Take the leap - Do cool science


Bronco Space and Stanford Student Space Initiative Teams together after AOS

# Thank You For Listening!

# Any Questions?


Nicole Maggard: crmaggard@cpp.edu Amanda Ewing: anewing@cpp.edu

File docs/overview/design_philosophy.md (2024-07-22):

# Why PROVES? 
When designing the PROVES kit we wanted to emphasize a few things: 

- **Simplicity**
- **Affordability**
- **Accessibility**

When designing the PROVES 1U CubeSat Kit we wanted to remove as much complexity as possible from the design. This is mainly due to the pains that we experienced when working with PyCubed based satellites like BroncoSat-1, Pleiades - Yearling 1, and QubeSat from UC Berkeley. Having to deal with a rats nest of wires and hundreds of pages of assembly documentation not only seriously slows down the integration process, but also introduces way more potential points of error. 

Complexity
<p align="center">Figure 1: This is what we are trying to avoid!</p>

So enter the original premise of the Pleaides Rapid Orbital Verification Experiment System (PROVES) Kit! The idea here was to try and remove as much complexity from the satellite as possible in order to make it as straightforward and easy to work with as can be. We needed to set some kind of measurable benchmark for whether or not we achieved this goal, so we decided to go for two things: 

1. **The CubeSat Bill of Materials shall cost no more than $1000.** 
2. **It shall be possible for two people to build the entire CubeSat from the kit components in one day.** 

Both of these requirements became the guiding star by which we designed the PROVES Kit over the last couple of years. 

### But Why CubeSats at All? 
In some ways the humble CubeSat (at least in the United States) is on something of a decline. This is evidenced by year over year declining attendance for the annual CubeSat Developer's Workshop in San Luis Obispo (while the annual SmallSat conference in Logan has consistently grown year over year) and also in signals such as the lack of robust funding opportunities for CubeSat scale missions. 

Although CubeSats have truly revolutionized the space community through drastically lowering the barier to entry in terms of launch cost, we believe much of this decline can be attributed the realization that CubeSats (to date) have not been able to drastically reduce the overall cost of a space mission. Although the Price per Kilogram to orbit has significantly come down in recent years (especially thanks to SpaceX Rideshare missions) the overall cost of conducting a space mission has not yet reduced to the point where it is generally accessible for academia to conduct them. 

#### New Space is Priced for Venture Captial 

Although the price per kilogram to get something to orbit has come down significantly in the last few years it is still a very long way away from being affordable. With the commerical rate to deliver CubeSats to orbit hovering around $50k / U, launch costs fit decently inside multi-million dollar venture captial rounds, but will quickly blow through grants and other forms of funding for innovative research that don't require a 100x potential upside.

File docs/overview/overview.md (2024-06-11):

# A PROVES Kit Overview
The PROVES Kit blends Open-Source Hardware and Software. The Hardware developed includes the entire educational satellite structure, brackets, and printed circuit boards. One of the major issues that we sought to solve with the kit was to develop a single solution for an end to end space mission engineering education. Many other open source projects avalible to the community only feature a single element, like just a radio or just a flight computer. 


<p align="center">Figure 1: The Yearling-2 Satellite</p>

## Flight Heritage
In order to ensure that the educational experience provided by using a PROVES Kit here on Earth is as authentic as possible we strove to fly it in outer space and verify that something can indeed be built with a BOM cost of less than $1k and do all of the core functions of a satellite. 

## Pleiades - Yearling: The Chaotic First Attempt 
***
We began this process with Pleiades - Yearling, which was conceived in Feburary 2022 as the brain child of Michael Pham and Megan Beck. This satellite was hot on the heels of BroncoSat-1 and, inspired by our friends at PSAS, we first tried to use a modular backplane solution that we were going to call the Lovelace Architecture. 

??? note "FiFi for PROVES x Ember"
    Technically, the first flight of the PROVES kit was actually not to orbit, but on the Bronco Space Balloon Launch Vehicle! On the third official flight of the Bronco Space BLV (aptly named Cube Your Enthusiasm) a stripped down Yearling took to the skies in order to assist the fledgling Bronco Ember team in figuring out whether or not their chosen stepper motor would perform at 100,000ft. 

    Check out the post flight analysis here: 
    

With a graceous endowment from our benefactor, Mike Beckage, we purchased a commerical rideshare opportunity for a 1U CubeSat and looked to the skies for the first journey of the PROVES Kit. Unfortunately a fully modular backplane system proved to be too complicated for us to finish developing in few short months we had from signing the launch contract to launch day. As a result, we did a massive rescope and brought back the PyCubed architecture (at the time in newly minted V5 form!) to pilot our ultra-low cost satellite. 


<p align="center">The Yearling Mega Breadboard</p>

We didn't really have a whole lot of money to play with or deep engineering talent to pull it off, so we went as cheap and simple as possible. This manifested in even going as far as soldering Adafruit sensor breakout boards to every face of the satellite to try and save as much engineering effort as possible! 

Pleiades - Yearling was launched in January 2023 alongside Sapling - Sempervirens from the Stanford Student Space Initiative. Despite successfully reaching orbit, the orbital transfer vehicle that we were hosted on suffered a critical systems failure after separating from the Falcon 9. As a result, the satellite was never deployed and is now stuck orbiting the Earth in its deployer pod.


<p align="center">Figure 2: Yearling 1 Being Loaded into the Deployer (Credit: Launcher Space)</p>

## Pleiades - Yearling 2: The Unexpected Second Try 
***
We never expected Yearling 1 to be Yearling 1. Kind of like how they didn't expect it to be World War I. Yearling 2 came very shortly after Yearling 1 was pronounced dead by failure of the deployment vehicle. We began R&D into an entirely new generation of the PROVES Kit on January 25, 2023 and had a completed Version 2 of the kit completed and qualified for spaceflight by March 1, 2023. This satellite went through two complete design iterations in that time and rolled in a significant amount of improvements over the Yearling 1 architecture. 

??? note "The Hunt for Red Sapling"
    One of the more interesting side chapters of the Yearling arc was a span of approximately one week in which we thought it was possible that Sapling - Sempervirens had slipped out from the confines of its orbital prison and was faintly transmitting from orbit! 


<p align="center">Figure 3: The Launch of Yearling 2 (Credit: SpaceX)</p>

This satellite was launched on April 8th, 2024, and contact was successfully made through the TinyGS network just 7 minutes after deployment. Unfortunately, contact was soon lost with the satellite before it could be transitioned into its amateur radio mission. Valuable experience and validation of our ultra-low-cost satellite thesis was nonetheless gained.


<p align="center">Figure 4: The First Packet From Yearling 2!</p>

## Pleiades - Squared: Third Time's the Charm! 
***
Due to the early loss of Pleaides - Yearling 2, our plan was to spend many months ironning out potential issues with the kit before attempting another spaceflight. This plan was totally cooked at the last minute though, when just a couple weeks after the launch of Yearling 2 we needed to do an emergancy delivery of a 1U satellite for a use it or lose it launch slot. 


<p align="center">The Journey of Pleiades - Squared</p>

This satellite was built, tested, and delivered for launch in only 1 calendar week. In order to get this done we did a rapid rebuild of the Yearling-2 engineering model to become SN11. The main updates from the SN10 that flew in April and this satellite were some small updates to the software, adding new redundant electrical connections, along with some additional glue and conformal coating of the boards.

This satellite was launched on June 12, 2024. Due to an unexpectedly early deployment from the host vehicle the satellite was actually lost in space for the first 5 hours of its mission life. Through a herculean emergency ground station effort from the amateur radio community though, contact was established and valuable mission telemetry was downlinked. This satellite unfortunately also suffered an early loss, but we were able to collect enough mission data to validate all of the core spacecraft systems. 


<p align="center">Figure 5: The Pleaides - Squared Satellite Right Before Integration!</p>

## Pleiades - Orpheus: Going Upstream
***
Scheduled to launch in Fall 2024, Pleiades - Orpheus will be the launch of a PROVES Kit based satellite from the Irvington High School Girls in STEM Club! Funded by the gracious donations of Christie English, the Orhpeus project will be a trail of flowing the educational potential of the PROVES Kit upstream to a group of students from a public highschool in Fremont, California. 

## The Pleiades Five: This is Getting Out of Hand
***
Now there are six of them! With its very confusing name, the Pleiades Five mission is tasked with taking six 1U CubeSats to orbit from five different colleges and universities (not including the lead, Cal Poly Pomona). This mission was selected in the 2024 round of NASA's CubeSat Launch Initative (CSLI).

*[PSAS]: Portland State Aerospace Society
*[Lovelace Architecture]: Named for computer scientist Ada Lovelace and a callback to the roots of our tech stack in the Adafruit ecosystem.

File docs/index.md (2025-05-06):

# Welcome to the PROVES Kit!

!!! tip "Make Sure to Check Out Our GitHub!"

    All of our PROVES Kit Design Files and Software is Availible on [GitHub](https://github.com/proveskit) under Open Source Licenses. We welcome interested users and contributors to take a look and get in touch! 

The Pleiades Rapid Orbital Verification Experiment System (PROVES) 1U kit is intended as an education first option for members of academia and industry who look to be first time or returning CubeSat developers. 
Picture of SN11
<p align="center">Figure 1: A Picture of Pleiades - Yearling SN11</p>

## Trials and Tribulations in CubeSats
Hey you! You’re finally awake. You were trying to cross the border into CubeSats too weren’t you? Walked right into all the complexities and costs and wondering what even is a quasi-static load? Just like those guys over there.

We were right where you were not too long ago. As founding members of Bronco Space at Cal Poly Pomona we started our journey into the land of CubeSats as a group of extremely naive undergrads in Spring of 2019. We wanted to bring something with our names on it and get it to outer space by 2022, whatever it took. How hard could it be? 

The First Ever Bronco Space Team
<p align="center">Figure 2: That Extremely Naive and Ambitious Group With Their First Creation</p>

Well, it turned out to be the most difficult thing that any of us had ever undertaken in our entire lives. Maybe even the hardest thing ever done at our university in all time. We had to fight against a complete lack of institutional knowledge or support, a complete lack of funding, and a global pandemic to get our first satellite BroncoSat-1 to orbit in May of 2022. Overcoming all of that just for it to not work. Dead on arrival, not even a peep. 

BroncoSat EM and FM
<p align="center">Figure 3: The BroncoSat-1 EM and FM</p>

By then our little student club had managed to carve out an existence as a small lab at Cal Poly Pomona, and we managed to persevere through to doing NASA backed instrument development and many more satellites on their way to space. We bet the farm on BroncoSat-1 and it still worked out despite the on-orbit failure, but it could have very easily gone the other way and been the end of our dreams of space. Most teams don't aren't able to catch that lightning in a bottle intersection between talent, opportunity, and luck to survive this long. 

## The PROVES Kit: Past, Present, and Future
The Yearling Team
<p align="center">Figure 4: The Team That Built Yearling</p>

This is what inspired us to dream of a world where the CubeSat developer never has to wonder whether or not their satellite will work. They would only have to ask “how well will my satellite work.” The PROVES CubeSat Kit is just the beginning of how we are planning to make this world a reality. Inspired by the work of open source space community pioneers such as Max Holliday, the Stanford Student Space Initiative, the Portland State Aerospace Society, and the Hawaii Spaceflight Lab, the PROVES CubeSat Kit is just the beginning of how we are planning to make this world a reality.

The Pleiades Five Team
<p align="center">Figure 5: The Future in the Pleiades Five</p>

The Pleiades - CubeSat Cluster and the Yearling line of satellites was where we sought to lay the ground work for a radically low cost and open source CubeSat architecture. Now we invite the rest of the New Space community to join us in our quest for a more open, accessible, and successful future in the stars! 

!!! tip "Interested in Getting a Kit?"
    We currently are accepting orders for [Flight Controller Dev Kits](https://095240-c9.myshopify.com/products/flight-controller-board) and [full PROVES Kits](https://095240-c9.myshopify.com/products/proves-kit-reservation). Check them out!

    P.S. we are also selling a [CubeSat Plushie](https://shop.proveskit.space)! 

## Documentation Layout
This documentation site is split into five sections: 

- **Overview:** Detailing the general background and flight heritage of the PROVES Kit.
- **Quick Start Guide:** Which presents the key design decisions that have gone into the PROVES Kit.
- **Assembly Guide:** A chapter by chapter walkthrough of building a PROVES Kit. 
- **Core Documentation:** Detailed accounts of the components of the PROVES Kit. 
- **Publications:** A record of the presentations and papers presented at conferences and workshops regarding the PROVES Kit. 

Also be sure to take a look at our [quick reference](https://docs.proveskit.space/en/latest/core_documentation/quick_reference/) page in case you're just looking for some handy tools!

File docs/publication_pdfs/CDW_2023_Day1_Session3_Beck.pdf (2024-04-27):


# PROVES

# A Low-Cost Educational CubeSat Kit

Bronco Space - CPP

Megan Beck, Michael Pham

TABLE OF CONTENTS

# WHAT WE’VE BUILT

### The PROVES 1U kit

# OUR STORY

### Bronco Space as a

### student organization

# WHERE WE’RE GOING

### Opening the door to

### space


# Our Story

How we started.


# Bronco Space

## Cal Poly Pomona Student-Led Organization

# BRONCOSAT-1


# What we gained

# 1.5U CubeSat

$120k Cost (launch not included)

2 years from concept to launch

Institutional knowledge

Technical and programmatic skills

Industry connections

# LESSONS LEARNED


## Space is expensive

Iterations and

mistakes become

very costly

## Space is hard

Especially for

undergraduate

students

## Space is important

Hands on learning

and real experience

# PROVES


## Pleiades Rapid Orbital Verification

## Experimental System

# Design Philosophy


## Built by students, for

## students

## - Openness

## - Simplicity

## - Ease of assembly

## - Short timelines

## - Mass production

# OUR LAUNCHES


## Transporter 6

January 2023

Deployer malfunction

## Transporter 7

April 2023

Success!

## BroncoSat-1

# 10 months & $240k


## PROVES-Yearling 1

## PROVES-Yearling 2

# 6 months & $48k 1 month & $32 k


# FOR LESS THAN $1,000, STUDENTS CAN BUILD A SATELLITE


# What Next?

# Expanding access to space

# Pleiades Five


## Collaborative PROVES kit constellation

Stanford

SSI

Columbia

Space Initiative

Harvard

SEDS

Texas State
University

Mt. Sac

Artemis

Questions?; Contacts:; Megan Beck - meganbeck2019@gmail.com; Michael Pham – mlpham@cpp.edu

Thank you to SlidesCarnival for the presentation template

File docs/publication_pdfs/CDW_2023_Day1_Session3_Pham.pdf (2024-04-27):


## Academic CubeSats are the Stroads of the Space Industry

Bronco Space

California State Polytechnic University, Pomona

For Public Release – Does Not Contain Controlled Information

April 25, 2023

# About Bronco Space


- Bronco Space is a mostly undergraduate student organization at Cal Poly Pomona
- Founded in 2019, Bronco Space has run the entire gamut from starting at zero to becoming the leading space technology group at Cal Poly Pomona

# Bronco Space’s Satellites


- In the last calendar year our organization has delivered three unique CubeSats for launch to LEO, all on commercial launch services
- The satellites have trended to be significantly cheaper and faster with each iteration

# What is a Stroad?


A Street | A Road
- A road is a throughfare for getting from one place to another
- A road is ideally high speed, low density, and few people (if any) linger in a road
- A street is a place
- Streets are ideally low speed, high density, and provide a venue for people to live, work, and recreate

# How Academic CubeSats are Like Stroads

The Stroad | The Academic CubeSat


- Tries to be an educational tool that provides unique learning to students while also being a novel and high-risk research instrument
- Often results in a space mission that does a mediocre job of being both or blocks the mission from reaching launch at all


- Tries to be a place where people exist and interact, while also trying to provide quick transportation from one place to another
- Results in a development that performs poorly in both regards, is economically disadvantageous, and is significantly more dangerous

# How Academic CubeSats are Like Stroads

- Tries to be an educational tool that provides unique learning to students while also being a novel and high-risk research instrument
- Often results in a space mission that does a mediocre job of being both or blocks the mission from reaching launch at all


- Tries to be a place where people exist and interact, while also trying to provide quick transportation from one place to another
- Results in a development that performs poorly in both regards, is economically disadvantageous, and is significantly more dangerous
The Stroad | The Academic CubeSat

# Case Study 1: GWSat


- Selected for CSLI in 2018
- No known manifest as of Spring 2023
- Suffered loss of institutional knowledge and momentum
- Complex propulsion related mission added significant overhead on student team

# Case Study 2: The QubeSat


- Selected in the 2020 round of CSLI
- Launched on the failed Astra LV-0008
- Quantum Gyro payload was dead on delivery
- Team rated only 5% chance of success, but 5% in space is better than 0% from the ground

# Case Study 3: OreSat-0 and OreSat-1


- OreSat-1 selected for CSLI in 2017
- Still unmanifested as of Spring 2023
- Repeated delays due to payload complexity
- OreSat-0 Launched in Spring 2022
- Manifested commercially
- Successful mission thanks to massive descope
- Example of a resilient team with strong lineage

# Case Study 4: BroncoSat-1


- BroncoSat-1 selected for free launch by Momentus in July 2020
- Initial delivery of the satellite in April 2021
- Program cost of BroncoSat-1 tripled vs original budget during course of program
- Launch in May 2022
- Satellite was DoA due to failure of COTS comms system

# What Should an Academic CubeSat Be?


- Perceived need for a high performing mission causes universities to over scope
- Costs are often poorly understood, and way underestimated
- Revolving door turnover in academic projects torpedoes productivity on multigenerational programs
- Siloed development and a lack of community knowledge leads to many mistakes being made multiple times

### Current Issues

# Recommendations for the CubeSat Community


- Push an understanding of Academic CubeSats as primarily or purely educational tools
- Discuss cost more openly and drive for CubeSats to become more accessible through significantly lower cost
- Reduce the timeline of academic CubeSats to align them with other successful student programs
- Promote and participate in collaborative channels and share data and designs openly
- Support open CubeSat architectures!
- Like the 1U PROVES Kit

### Potential Solutions


Questions?
Contact: mlpham@cpp.edu | mcbeck@cpp.edu

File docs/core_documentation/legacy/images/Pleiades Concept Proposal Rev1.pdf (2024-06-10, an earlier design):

Pleiades CubeSat Cluster Concept

# Pleiades CubeSat Cluster

## General Concept Proposal


Rev 1 - Initial Release
Published August 4, 2021

## Developed by Blue Dot Consortium Members:

Cal Poly Pomona Bronco Space, Portland State Aerospace Society, Stanford Student Space Initiative, and the Hawaii Space Flight Lab

Pleiades CubeSat Cluster Concept

Mission Statement:
The Pleiades CubeSat Cluster is a proposed flight of eight Cube Satellites to provide essential flight heritage for open CubeSat architectures, investigate methods to establish relative navigation & in space situational awareness for collaboration in Small Satellite Swarms, and create educational pathways for students towards the future of the New Space Industry. The Pleiades Cluster is developed by members of the Blue Dot Consortium, an international inter-university network of over 30 student-led or student focused CubeSat development groups.

CubeSat Mission Parameters

Satellite Integrator | Estimated Mass | CubeSat Size | Desired Orbit | Acceptable Orbit | Expected Mission Life
PSAS | 5.5kg | 3U | Attitude: 450km Inclination: 98° | Attitude: 300km - 550km Inclination: 45° - 100° | 1 Year
PSAS / CPP | 5.5kg | 3U
SSI | 1.5kg | 1U
SSI | 1.5kg | 1U
SSI / CPP | 1.5kg | 1U
HSFL | 1.5kg | 1U
HSFL | 1.5kg | 1U
HSFL / CPP | 1.5kg | 1U
Total | 20.0kg | 12U
*Note in order of appearance: PSAS = Portland State Aerospace Society, CPP = Cal Poly Pomona Bronco Space, SSI = Stanford Student Space Initiative, HSLF = Hawaii Space Flight Lab
Points of Contact
Organization | Name | Title | Phone | Email
CPP -Prime Integrator | Michael Pham | Student Research Director | (408)839-0809 | mlpham@cpp.edu
PSAS -OreSat Lead | Andrew Greenberg | PSAS Faculty Advisor | (503)708-7711 | adg4@pdx.edu
SSI -PyCubed Lead | Flynn Dreilinger | GNC Lead and Operations Lead | (415)530-9000 | flynnd@stanford.edu
HSFL -Artemis Kit Lead | Amber Imai-Hong | Artemis Kit Engineering Lead | (808)987-0567 | amber@hsfl.hawaii.edu

Pleiades CubeSat Cluster Concept

Proposal Abstract | 4
The Pleiades CubeSats: A Diverse Fleet of Open Architectures | 4
Enabling Tech Tests: Situational Awareness and Formation Flight | 4
Pathways of the Future: Enabling and Enhancing Education | 4
1 Why is the Pleiades Cluster Needed? | 5
2 Primary Mission: Proving and Improving Open Architectures | 7
2.1 The OreSat Bus as a High Performance Open Architecture | 7
2.2 PyCubed Based Satellites for Open Sourced Simplicity | 9
2.3 The Artemis CubeSat Kit | 10
2.4 Enabling CubeSat Production at Scale for Universities | 10
3 Extended Mission: Demonstrating In-Space Situational Awareness and Satellite
Cooperation with Mesh Networking | 10
3.1 Swarms, and Why They Need Situational Awareness | 11
3.3 Optical Acquisition for In-Space Situational Awareness | 11
3.4 Ad-Hoc Mesh Networking for Awareness & Collaboration | 12
4 Creating Pathways for the Future Space Industry | 13
4.1 Directly Enabling More Student Participation in CubeSats | 14
4.2 Indirectly Enabling Enhanced Pathways to the Space Industry | 14
5 Implementation Plan | 15
5.1 Cluster Architecture | 17
5.2 Technology Development | 18
5.3 Integration & Test | 18
5.4 Outreach Activities | 19
5.5 Schedule | 19
5.6 Descope Plan | 20
6 Proposed CONOPS | 20
6.2 Operations Phases | 20
6.3 Operations Architecture | 22
7 The Pleiades Team | 23
7.1 Cal Poly Pomona’s Bronco Space | 23
7.2 Portland State Aerospace Society | 24
7.3 Stanford Student Space Initiative | 24
7.4 Hawaii Space Flight Laboratory | 25
8 Cost Estimate | 26
8.1 Simplified Cost Projection Justification | 26
8.2 Potential Funding Sources | 27
9 Appendix A - References | 29
10 Appendix B - Alpha Schedule Definition | 30

Pleiades CubeSat Cluster Concept

# Proposal Abstract

The Pleiades CubeSat Cluster is a large-scale inter-university collaboration to test open architectures for small satellites, develop methods for safer and more capable formation flight of spacecraft, while also creating robust pathways for the future of the New Space Industry. This is all set to be accomplished through the design, integration, test, and on-orbit demonstration of a fleet of multiple CubeSats, simultaneously deployed by a single launch. The Pleiades Program seeks to combine the unique satellite architectures, expertises, and resources of a diverse consortium of US universities into this satellite fleet to encourage and create the collaborative communities that are a hallmark of space exploration.

### The Pleiades CubeSats: A Diverse Fleet of Open Architectures

The primary objective for the Pleiades Program shall be to flight test select, prevailing, open architectures for CubeSat development. As a consortium of university CubeSat developers, one of the universal frustrations is the highly proprietary and closed nature of the traditional space industry. This often results in high costs, long lead times, and confusing interfacing between components from different manufacturers - all factors that are incompatible with the academic space and are believed to hamper the growth of the CubeSat market.

Three different architectures shall be included within the scope of Pleiades: OreSat, PyCubed based, and the Artemis Kit. Each architecture represents a different design philosophy and the three together reflect the three major schools of thought for CubeSat hardware design (backplane / card cage, single board, and PCI/104 stackup respectively). The cluster currently intends to incorporate 2x OreSat Type 3U CubeSats, 3x PyCubed Type 1U CubeSats, and 3x Artemis Kit Type 1U CubeSats for a total of 12U’s of payload. The Pleiades Cluster therefore intends to not just provide an opportunity for valuable flight heritage of these architectures, but also a test batch manufacturing methods for each architecture that may greatly reduce cost.

### Enabling Tech Tests: Situational Awareness and Formation Flight

The secondary objective for Pleiades shall be the development and demonstration of new methods for satellites to establish in-space situational awareness and collaboration when in a formation flight. This is intended to be accomplished through the use of inexpensive cameras, optical footprint enhancers, and radio techniques using a wireless mesh network. Success in establishing in-space situational awareness may have significant broader impacts on collision avoidance for spacecraft fleets. The ability to characterize the size and shape of a swarm, while also facilitating inter-craft communication and coordination, will enable greatly enhanced exploration of the solar system with multipoint science investigations.

### Pathways of the Future: Enabling and Enhancing Education

The final objective of the Pleiades shall be to inspire, enable, and enhance educational outcomes for students entering the Space Industry. As a student initiated, and university focused project, the Pleiades team believes that access to comprehensive hands-on learning experiences are indispensable in preparing for the future. This is accomplished by providing opportunities for students to participate in the cutting edge of satellite development. Additionally, the culture of collaboration inspired by this inter-university team will be essential for building a more united and cooperative future.

Pleiades CubeSat Cluster Concept

## 1 Why is the Pleiades Cluster Needed?

With the exponential trajectory of the Small Satellite Industry, it is more important than ever to take the appropriate steps to prepare for a safe and secure future. New launch providers continue to enter the market and enable a supply of available rides to orbit like never before. Thus it becomes increasingly important to ensure development and support of open, efficient, and trusted architectures for the creation of robust small spacecraft that can meet the rising supply of launches with appropriate demand.

Although the SmallSat industry has seen major strides in recent years, with the launch of SmallSat constellations creating an over 2-fold increase in operational satellites since 2015 [1], the entry of new developers into the industry still faces many roadblocks. Roadblocks that are especially apparent to university class developers, who almost universally struggle with prohibitively high costs, exceedingly long lead times, and the highly proprietary & closed source nature of the traditional Space Industry. Compounding these challenges, unlike most other industries, there exists virtually no hobbyist or amateur community that can act as an on-ramp for new entrants. Considerations of how to design for or operate in a space environment are also usually devoid from formal education programs until the graduate level. This leaves an immense burden on university class developers to either: find huge amounts of funding to sub-contract satellite fabrication to a commercial company or commit huge amounts of time and talent (often unpaid and inconsistent student talent) to create the institutional knowledge and infrastructure for a space mission from scratch.

A 2019 study by a multi-university team, led by Lucinda Berthoud and featuring the prolific Dr. Michael Swartwout (who keeps one of the most detailed CubeSat databases in existence), found that 55% percent of universities have only ever flown a single mission and only 17 independent institutions in the world can be considered “prolific,” with four or more missions (N=192). This study also found that among the non prolific independent universities (universities programs that are not proxies for a national government’s laboratory) there was an abysmally low 9.8% rate of full mission success from 2014 - 2018 [2]. When combined with the historically extremely high costs and immense technical challenge of executing a space mission, such a high failure rate has no doubt resulted in the death of many promising CubeSat programs.

Most of the universities that have achieved prolific status were only able to do so given the opportunity to repeatedly fly their architectures and improve through a cycle of failure, lessons learned, and iteration. This is extremely resource intensive and is often only possible with unwavering funding, unusually zealous program leaders, exceptional talent, or all of the above. It can be seen from the study’s data that once a program is able to graduate from growing pains to prolific status, a steady stream of delivered missions is almost assured. Out of the 428 university class missions flown up to 2018, 197 (46%) came from prolific universities [2].

So it appears that once a program is able to design, test, and iterate their spacecraft heritage over just a handful of flights, continued participation in the Space Industry is almost assured. The unfortunate reality for many who start on this path though, is that after meeting, almost inevitable, failure with their first attempt their programs will also almost certainly fail to continue. Perhaps if there were platforms for new developers to adopt that ensure at least some core level of success, no matter their institutional heritage, it would be possible for many more groups to succeed. This could create a fast track, through the exceedingly difficult process of

Pleiades CubeSat Cluster Concept

bootstrapping a new flight architecture from scratch, and allow these groups to graduate into becoming prolific programs. Hence a need is established, for proven architectures that are not only readily available but also open to being accessed by all, no matter their institutional heritage or present resources. These architectures would also directly serve the industry by lowering failure rates and widening the potential demand for space exploration and exploitation.

One of the related effects of an exponential increase in launch availability, combined with more widespread mass production of satellites, will be the allure of conducting swarm or formation flight missions. This new class of mission involves multiple satellites launched simultaneously and collaborating in some way to complete the mission as a unified entity. Proposed concepts for these satellite fleets range from data relay networks that enable large savings in size, weight, and power (SWaP) to gravitational interferometry or advanced parallax observations. Unfortunately, these types of missions remain on the fringes of the state of the art until certain enabling technologies gain the flight heritage needed to be trusted on operational missions. Therefore, a need is established for the development and test of technologies that enable collaborative operations between groups of satellites.

Additionally, as the Space above us continues to fill with spacecraft, both the risk of in-space catastrophe and the promise of unlocking vast untapped capabilities blossom, with the growing market for formation flights of tens, if not hundreds or thousands, of spacecraft. To protect the common heritage of humanity, and enable its exploration on an unprecedented scale, enabling systems for in-space situational awareness and cooperative formation flight must be developed and demonstrated.
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

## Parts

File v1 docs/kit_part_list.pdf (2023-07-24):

Part Number | Part Descriptor | quantity | Included | Part Number | Part Descriptor | quantity | Included
0n0008 | Flight Computer | 1 | 0n0001 | Structure Halves | 2
0n0009 | Battery Board | 1 | 0n0002 | L-Brackets | 4
0n0010 | XY Solar Boards | 4 | 0n0003 | Card Brackets | 2
0n0011 | Z- Solar Boards | 1 | 0n0004 | Embedded Foot | 4
KXOB101K08F-TR | Solar Cells | 30 | 0n0005 | Non-Embedded Foot | 4
5040500591 | 5 position picolock headers | 4 | 0n0006 | Remove Before Flight Switch bracket | 1
5040500291 | 2 position picolock headers | 2 | 0n0007 | Remove Before Flight Pin | 2
151320501 | 100mm 5 pos picolock cable | 5 | | m2.5x5 pan head T8 | 34
151320503 | 300mm 5 pos picolock cable | 2 | | m2.5x5 button head T8 | 16
5040510201 | 2 position picolock connector | 10 | | m2.5x10 or m2.5x8 T8/T6 | 18
151321202 | 100mm 12 pos picolock cable | 1 | | m2x20 pan head Philips | 2
3245 | thermocouple | 1 | | m2.5 lock nut | 18
COM-11288 | patch heater | 1 | | m2 lock nut | 2
18650 | batteries | 4
1760510000 | 2 position screw terminal | 1
1051640001 | Micro USB | 1
VL6180XV0NR/1 | LiDAR | 1
HHM1589D1 | Balun | 1
RFM98/RFM95 | Radio Module | 1
4754 | IMU | 1
4399 | Stemma QT Cable | 1
D2F-5L3 | Foot Switch | 2
SS-5GLT | Remove Before Flight Switch | 1
APAN3109 | Relay | 1
1049 | Battery Holders | 2

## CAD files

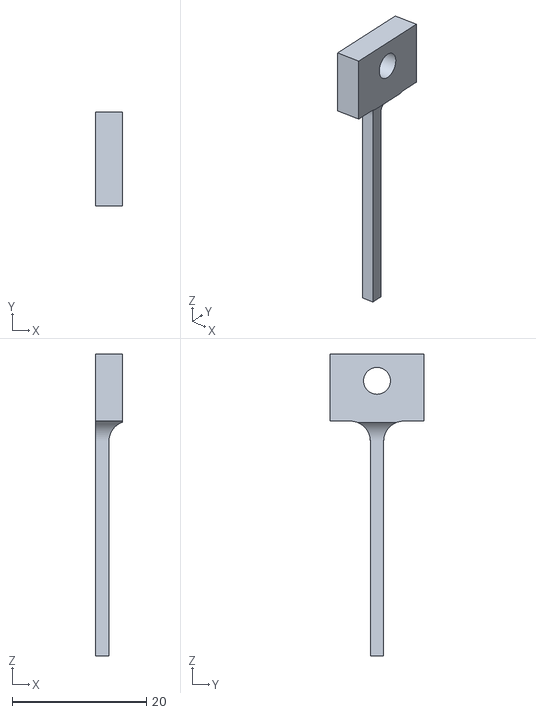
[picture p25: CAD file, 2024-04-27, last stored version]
PROVES RBF.stl
4.00 x 14.0 x 45.0

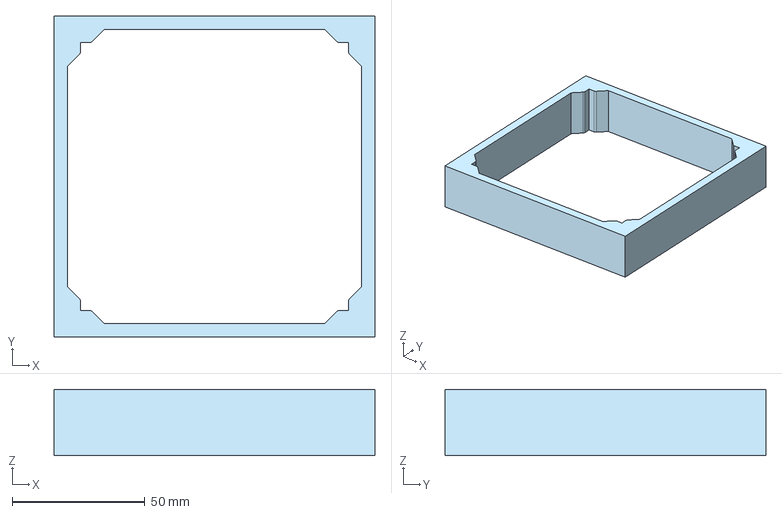
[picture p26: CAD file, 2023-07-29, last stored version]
jig.step
121.0 x 121.0 x 25.0 mm

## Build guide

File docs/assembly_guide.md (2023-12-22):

<h1 align="center">The PROVES Kit</h1>
<h2 align="center">Assembly and Integration Guide</h2>

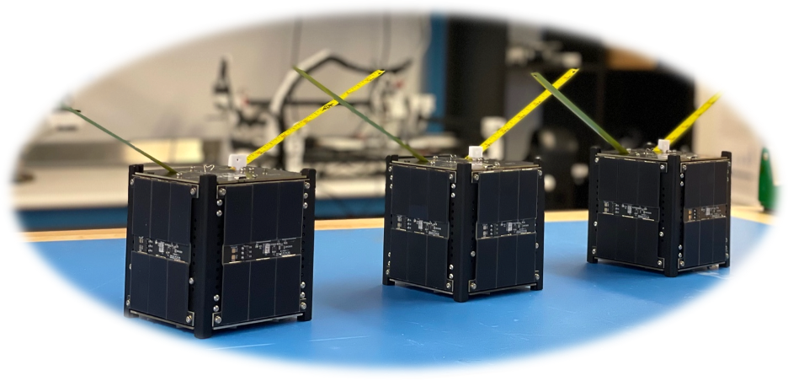
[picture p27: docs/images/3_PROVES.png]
Three PROVES Kits


<p align="center">Version 0.1 Pre-Release</p>

Welcome to the assembly and integration guide for the PROVES (Pleaides Rapid Orbital Verification Experiment System) 1U CubeSat Kit. In this guide we will detail all the steps needed to take your kit and make it a functioning satellite!

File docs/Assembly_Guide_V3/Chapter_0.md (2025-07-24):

# Chapter 0: Parts and Tools

## Parts

In addition to the included parts of the kit, the User will be required to obtain:

- 1 Micro SD card
- 1 Micro Type B USB cable
- 1 Tape measure
- Kapton tape
- At least 56mm of 1mm heat shrink
- Pusher (3D printed piece or a long screw that fits in the foot)
- Blue Loctite (for final sat)
- 1 Jig

The jig can be obtained from our documentation repository at our [GitHub Organization](https://www.github.com/proveskit).

## Tools
The User will need the following tools prior to proceeding:

<div class="result" markdown>
- Soldering Iron
- Lead Based Solder
- 18630 batteries (ideally Panasonic NCR18650B)
- Reflow Oven
- Low Temperature Lead Based Solder Paste
- T6 Torx Head Screwdriver
- T8 Torx Head Screwdriver
- Phillips Head Screwdriver
- Flush Cutters
- Sandpaper or Dremel
- M3 hole punch
- Hammer
- Needle nose tweezers
- Loctite
- Space-rated glue
- Multimeter
- Power supply
- Proper protective equipment
- Sandpaper or Dremel

If you are confused about any of the wiring or need references, refer to the following GitHub repositories:

- [Flight Controller](https://github.com/proveskit/flight_controller_board)
- [Battery Board](https://github.com/proveskit/battery_board)
- [Faces/Z-board/Solar Boards](https://github.com/proveskit/solar_boards)
- [Antenna Board](https://github.com/proveskit/antenna-board)

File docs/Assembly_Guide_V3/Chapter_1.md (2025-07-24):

# Chapter 1: Flight Controller Board

In this chapter, the user will learn the proper steps to assemble a Flight Controller Board.

!!!Warning
    ***Before continuing:** it is important to note that gloves should be worn when soldering and it should be done in a well-ventilated area to avoid the harmful fumes.*

## Soldering the Radio Component
**1.** Place a piece of Kapton tape between the radio and the flight controller board. The exposed metal part on the underside of the module should be taped up with Kapton tape in order to avoid contact with the copper pads on the HopeRF footprint of the FC Board.

**2.** On the radio module, there is a dot on the metal side which should be next to the C15 connection. Tape down the radio module to ensure that it stays in place while soldering the pins of the radio module to the copper pads of the footprint on the FC Board. Once the radio module is aligned and secured, solder it.

*<p align="center">**Figure 1.1: Flight Controller Board with tape and pads labelled**</p>*
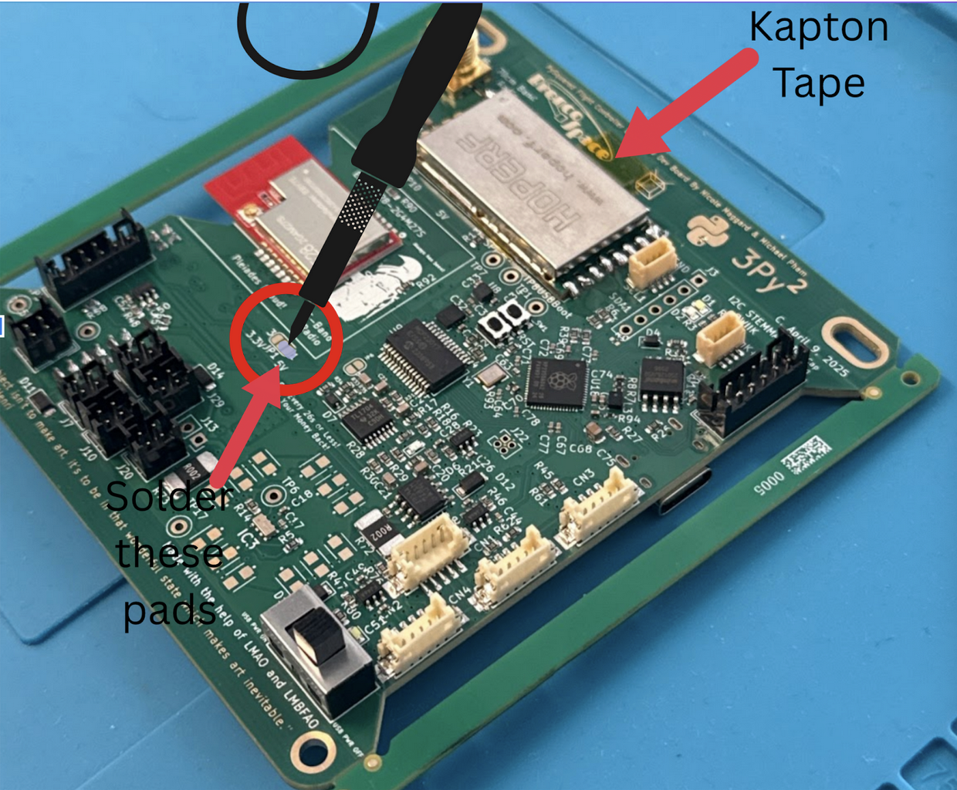
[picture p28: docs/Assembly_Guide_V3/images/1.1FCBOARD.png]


**3.** Locate the pads circled on Figure 1.1. Solder together the two pads located next to the 5V label in order to turn on the radio. Make sure not to put solder on the third pad.

**4.**  Plug in the flight controller board with a USB-C cable, and flip on the switch. Turn on the board switch. The flight controller board has an LED that turns on.

**5.** Next, follow the steps in the [Software Setup Guide](https://proveskit.github.io/pysquared/getting-started/). This will help you test the boards in the future steps.

!!!Note
    The rest of the tutorial is structured by showing you how to solder or assemble a board and then connect it to the flight controller board and test that it works. You will have to come back to the software, so keep it open (and you can keep the flight controller connected) or remember how to connect for the next time. You can also do all the builds and come back and do all the tests, but this will help you catch errors in assembly quicker.

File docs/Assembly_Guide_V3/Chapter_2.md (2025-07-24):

# Chapter 2: Face Assembly 
In this chapter the user will learn the steps to assemble the faces. There are 4 solar boards that go to the side of the satellite and a Z-board that goes on the bottom of the satellite. The antenna board goes on the top.

!!! Warning
    ***Before continuing:*** it is important to note that gloves should be worn prior to applying solder paste to avoid ingestion of a lead-based material.

**1.** Plug in connectors to the solar boards. Then plug all the solar boards into the flight controller board.

*<p align="center">**Figure 2.1: Face Boards Plugged In**</p>*
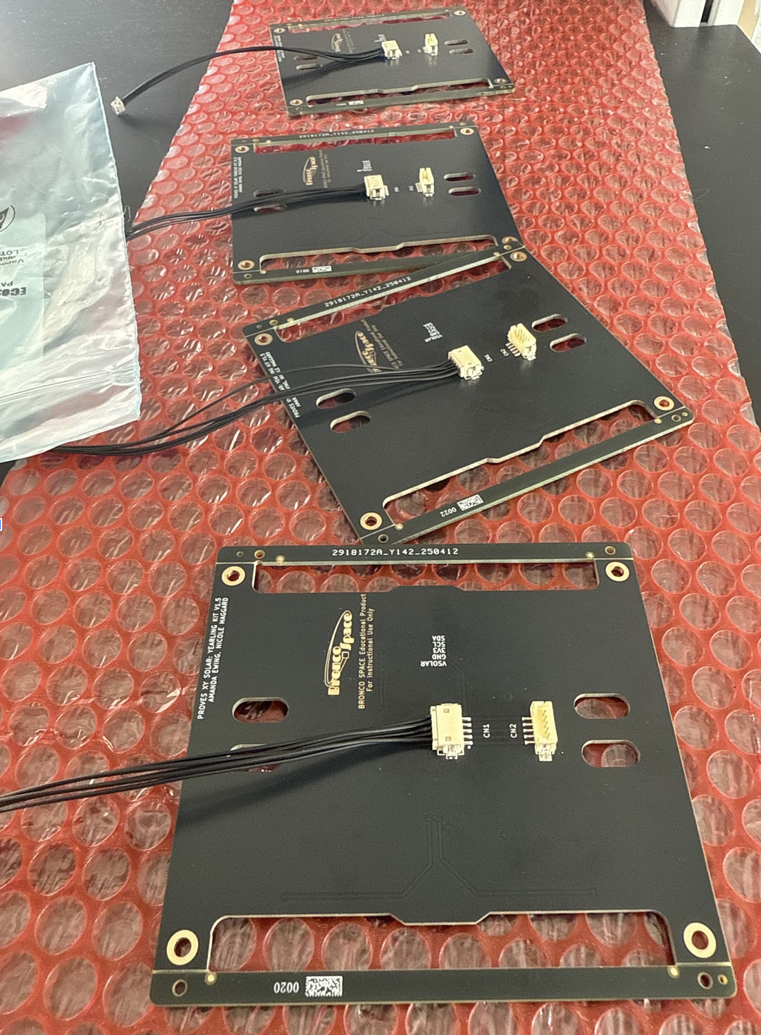
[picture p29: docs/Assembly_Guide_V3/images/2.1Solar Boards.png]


**2.** Now its time for the first test!

You can type `all_faces_off()` to turn the faces off and `all_faces_on()` to turn them back on again. You should observe the lights turning on and off.

*<p align="center">**Figure 2.2: Face Boards Plugged In**</p>*
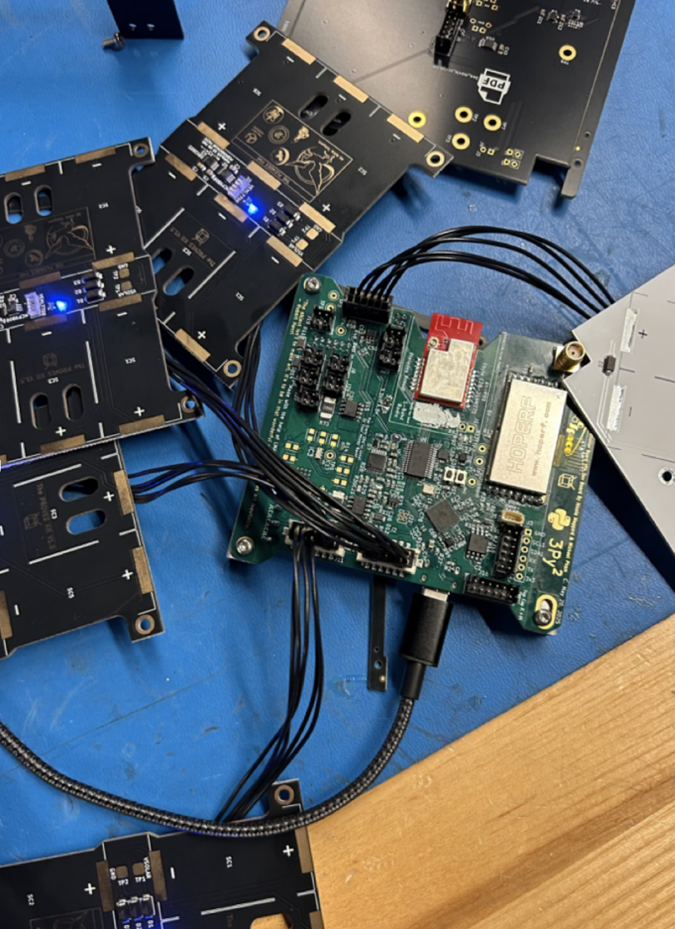
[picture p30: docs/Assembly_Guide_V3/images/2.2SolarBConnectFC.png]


Now to check the data that you get from the boards:

Type:

    `all_faces.face_test_all()`

This returns an array of arrays. The first 4 are the face boards and the fifth is the Z-board. Each board contains two values: [temperature, ambient light]. Shine a light on the different boards and run the commands again to see the numbers change and ensure the sensors are working.

!!! warning
    Test all sensors for full functionality prior to solar cell installation. If sensors are faulty and need to be reflowed or removed with a heat gun, the cells will be damaged in the process.

**3.** Next, add the solar cells to the solar boards.

First, check that the positive and negative terminals on the back side of the cells are matched with the plus and minus silk screened on the PCB.

!!!WARNING
    You **cannot** tell the orientation of the cell from the top of the cell, so make sure it is placed properly.

**4.** Apply Low Temperature Solder Paste to the pads on the Solar Board as seen in Figure 2.2.

For cells that are immediately next to each other, scoot them together so that the gap between them is as small as possible.

**5.** Reflow on low heat (the low temperature for the solder that you use is recommended) and do not touch until completely cool.

!!!WARNING
      Be very careful, it is easy to overheat the solar cells. Solar cells can’t exceed 175°C for over 50 seconds.

*<p align="center">**Figure 2.2: Solar Cells on the board**</p>*
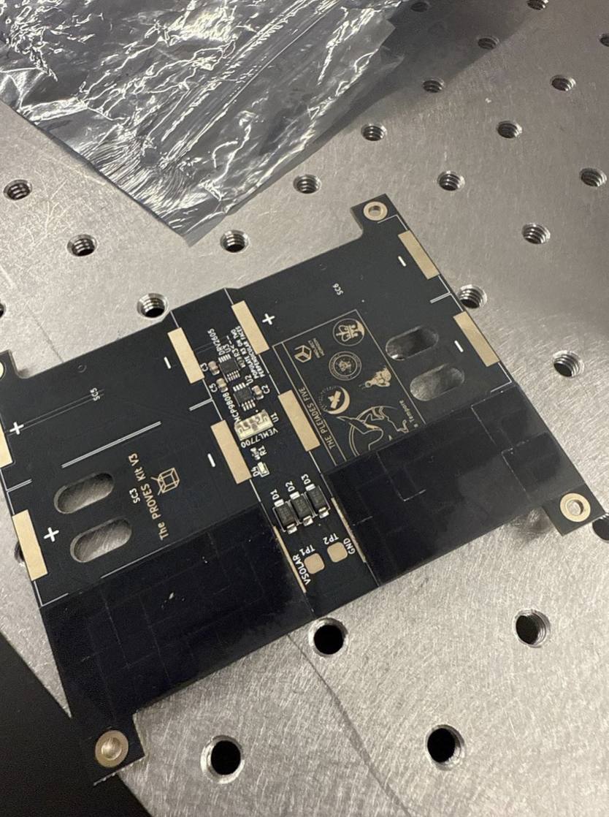
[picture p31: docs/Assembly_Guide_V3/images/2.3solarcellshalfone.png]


**6.** To test the connections, use a voltmeter to ensure each cell is connected and charges under light. You should see a voltage increase when the cells are exposed to light.

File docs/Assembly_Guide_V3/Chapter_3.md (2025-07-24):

# Chapter 3: Power Stop
In this chapter, the user will learn how to properly assemble the Power Stop. These go on four of the eight feet on the satellite and inhibit the satellite when it is not deployed.

!!!Warning
    ***Before continuing:** it is important to note that gloves should be worn when soldering and it should be done in a well-ventilated area to avoid the harmful fumes.*
**1.** Cut 7mm of black and 7mm of red heat shrink.

**2.** Insert heat shrink into the power stop harness and slide all the way to the end.

**3.** Apply flux to wire tips and power button ends.

*<p align="center">**Figure 3.1: Flux on Button**</p>*
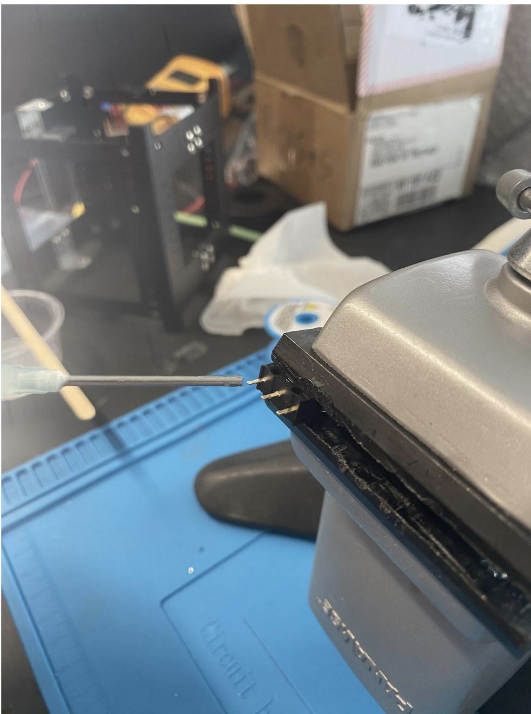
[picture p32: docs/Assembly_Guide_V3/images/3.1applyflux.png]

*<p align="center">**Figure 3.2: Flux on Wire Tips**</p>*
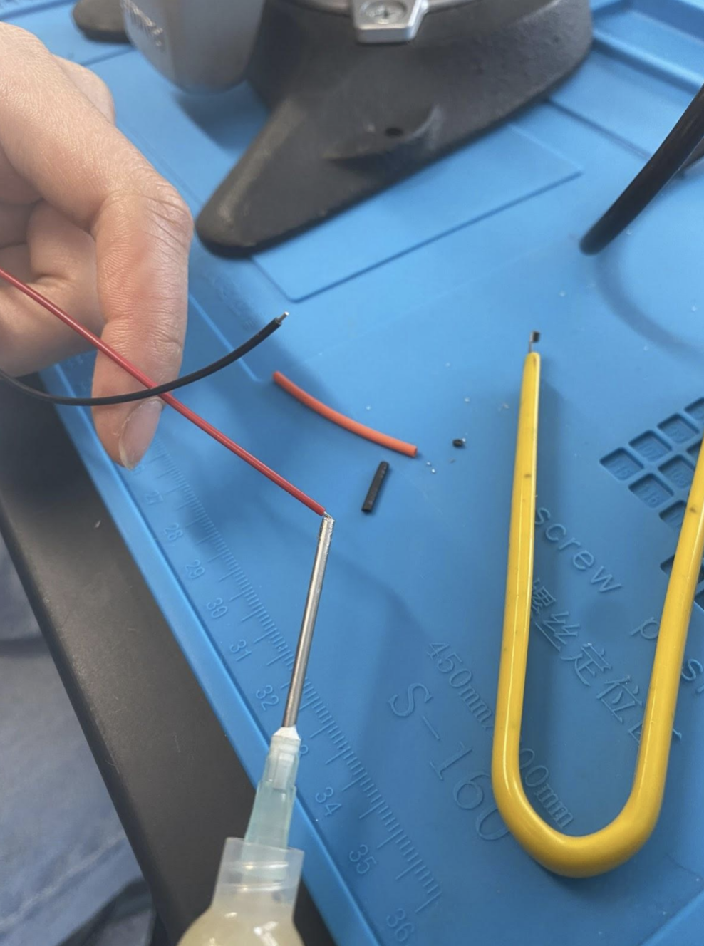
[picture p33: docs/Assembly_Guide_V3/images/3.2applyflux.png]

**4.** Apply solder to wire tips and power button ends.

**5.** Re-apply flux to wire tip.

**6.** C is the black wire; CN is the red wire. Solder the red wire to the pin labeled CN on the button. Solder the black wire to the pin labeled C on the button.

*<p align="center">**Figure 3.3: Completed Soldered Button**</p>*
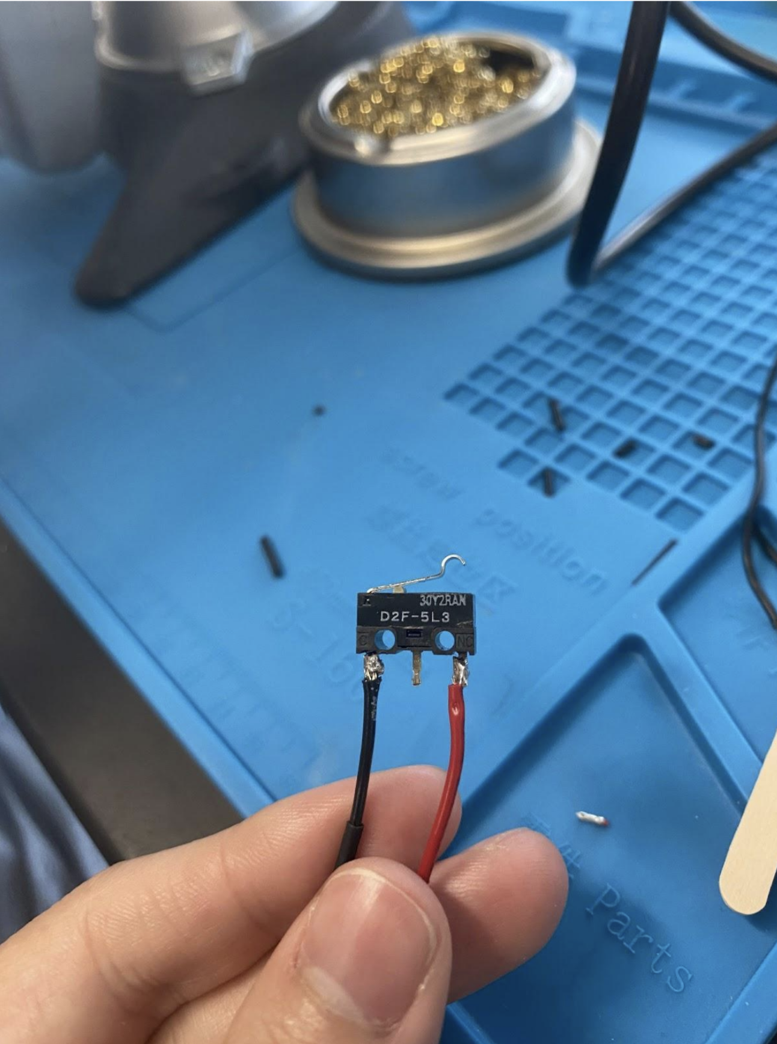
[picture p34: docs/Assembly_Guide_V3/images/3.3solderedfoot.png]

**7.** Clean tips with alcohol to remove flux, so that flux does not corrode metal. Then push shrink wrap onto the soldered ends, and shrink with a heat gun.
*<p align="center">**Figure 3.4: Heat Shrunk Button**</p>*
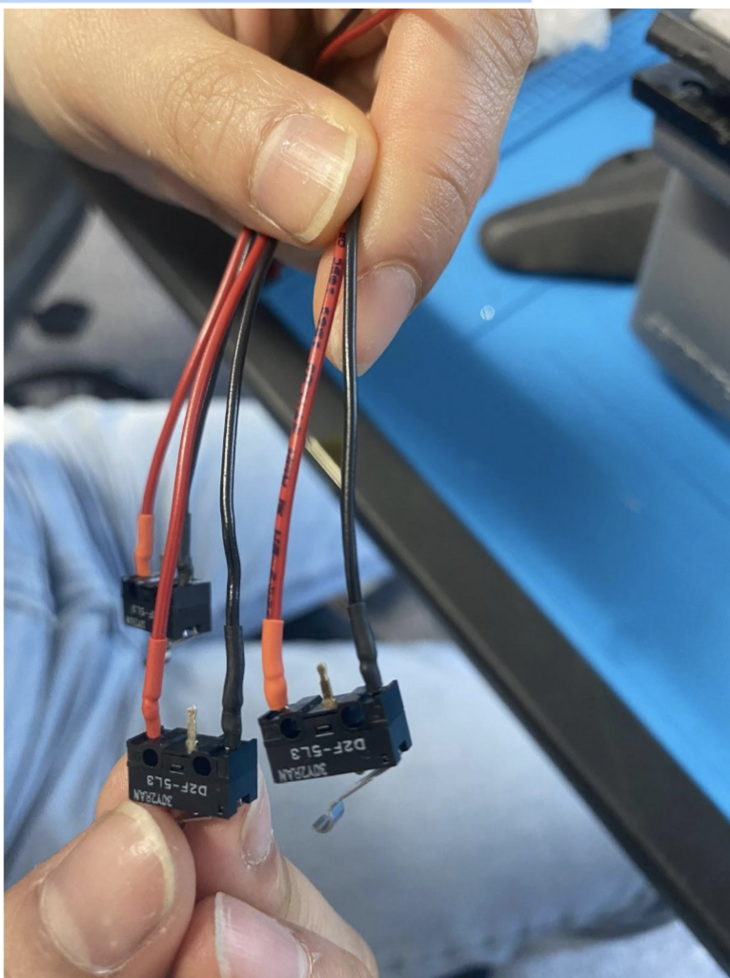
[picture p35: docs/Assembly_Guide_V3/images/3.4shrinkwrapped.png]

**8.** Insert pusher or screw into power stop harness casing.
*<p align="center">**Figure 3.5: Pusher Inserted**</p>*
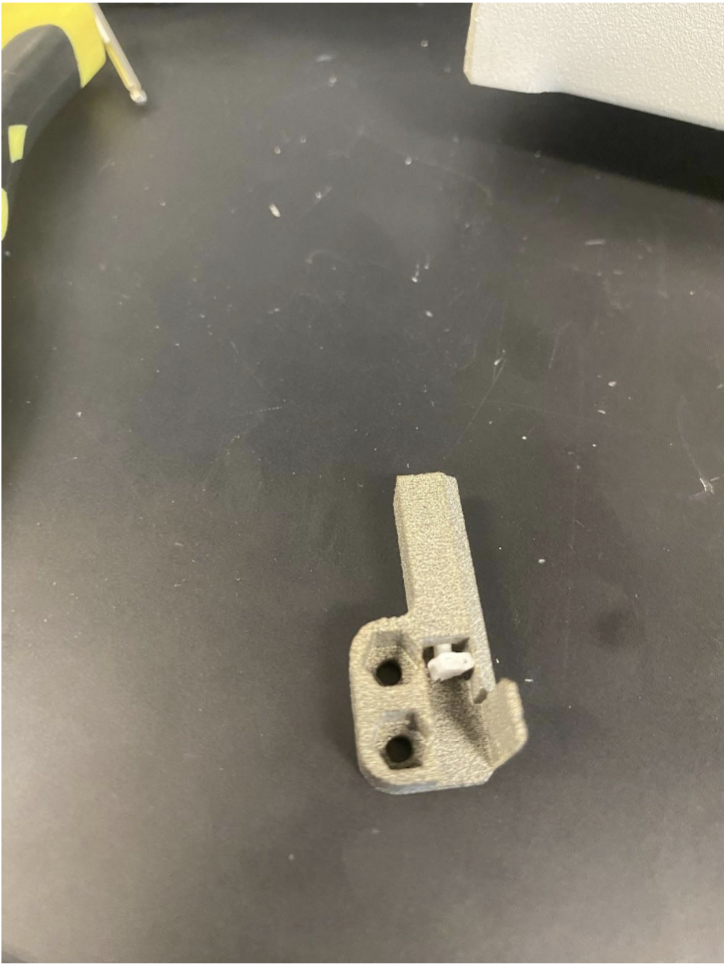
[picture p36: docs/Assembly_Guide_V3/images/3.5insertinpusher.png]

**9.** Assemble power stop harness into casing and glue tight. Use space-rated glue or epoxy. Follow the instructions on your glue.
*<p align="center">**Figure 3.6:  Final Assembeled Power Stop**</p>*
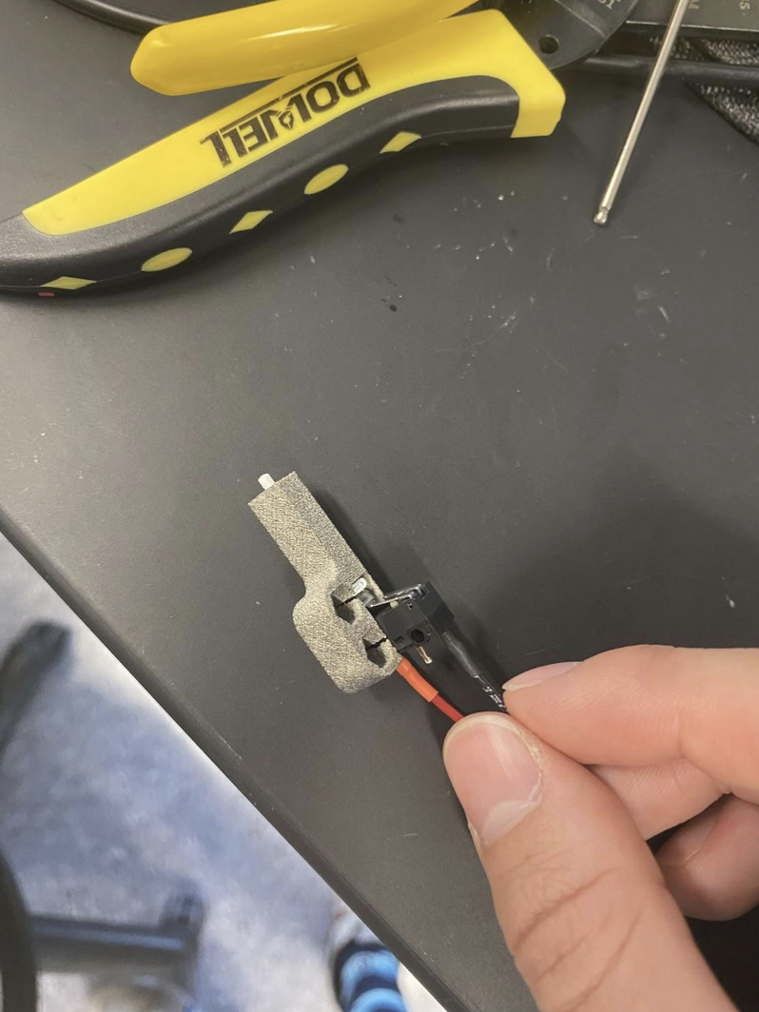
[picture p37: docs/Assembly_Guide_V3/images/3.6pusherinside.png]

**10.** Test the power stops by plugging them into the FC board and clicking them. Check that the light on the FC board blinks. This means the signal is going through.

**11.** Screw power stop onto CubeSat structure. It should not be possible to place the cases incorrectly, as if they are flush against the wall, they can only line up with their respective holes. Add nylocs, use the hex screws and a 1.5mm Allen wrench.
*<p align="center">**Figure 3.7: Foot Placed on Structure**</p>*
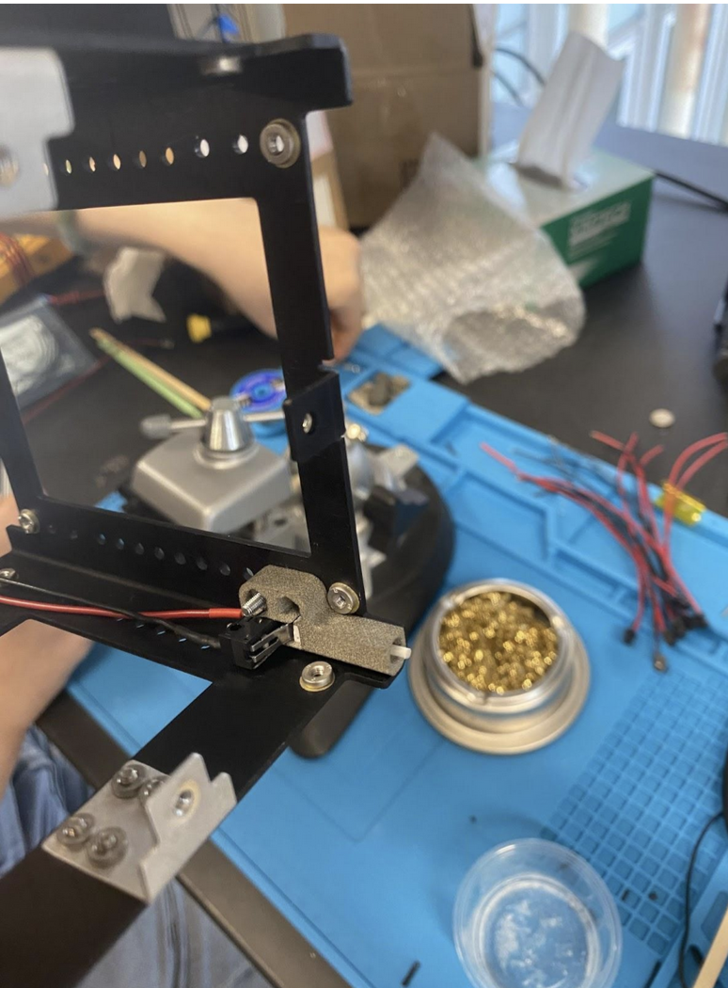
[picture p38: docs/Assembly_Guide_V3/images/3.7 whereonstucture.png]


Repeat these steps four times to make four power stops.

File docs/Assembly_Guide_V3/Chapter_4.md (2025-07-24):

# Chapter 4: Battery 
In this chapter, the user will learn how to assemble the PROVES Flight Controller Battery Board.

!!!Warning
    ***Before continuing:** it is important to note that gloves should be worn when soldering and it should be done in a well-ventilated area to avoid the harmful fumes.*</span>

**1.** Place the batteries into the battery holder. Make sure the positive and negative ends are correct.

**2.** Flip over the board to test the voltage. Take a voltmeter and put the ends on the areas on the back. Place the positive end on the point and test two points with the negative end.

*<p align="center">**Figure 4.1: First Test Position**</p>*
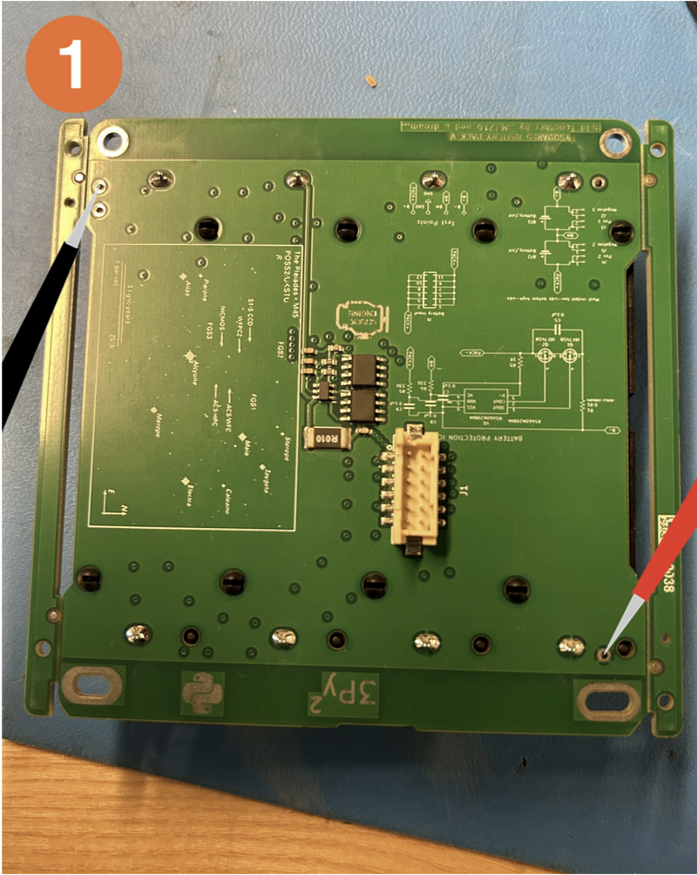
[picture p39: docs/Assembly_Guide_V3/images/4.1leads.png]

  
  *<p align="center">**Figure 4.2: Second Test Position**</p>*
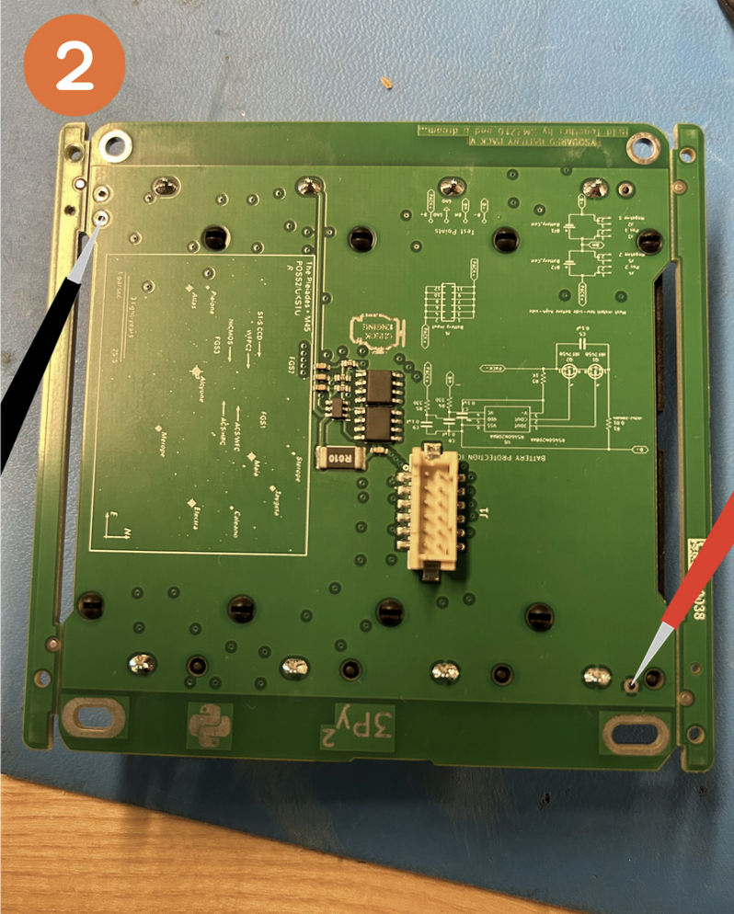
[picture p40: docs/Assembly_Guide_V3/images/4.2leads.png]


Both of the battery readings should be around 7.2V. If they are considerably less, charge or replace the batteries.

Both of the readings should read the same number. If they are unequal, you should take the batteries out and then put them back in.

**3.** Now plug the battery into the flight control board. Make sure your computer is connected to the flight controller board.

  *<p align="center">**Figure 4.3: Battery Board Plugged in**</p>*
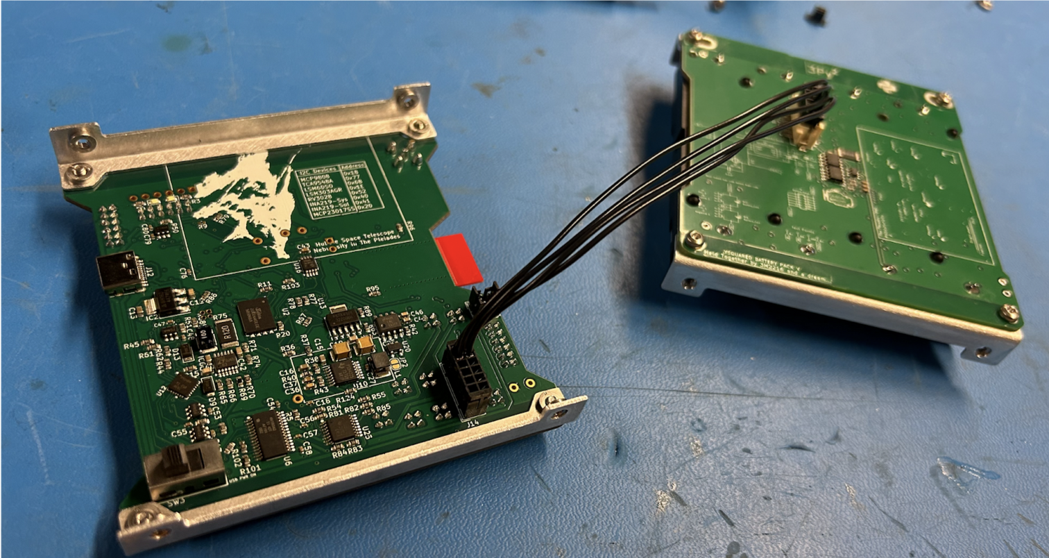
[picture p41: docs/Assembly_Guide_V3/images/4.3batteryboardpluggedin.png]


Also make sure the power stops are plugged in from the previous step! If not, the next step won’t work.

**4.** Run `battery_power_monitor.get_bus_voltage()` without the battery plugged in. Then plug it in (or vice versa). You should have ~7.2V when the battery is plugged in and significantly less when it is not.

  *<p align="center">**Figure 4.4: Example of code results**</p>*
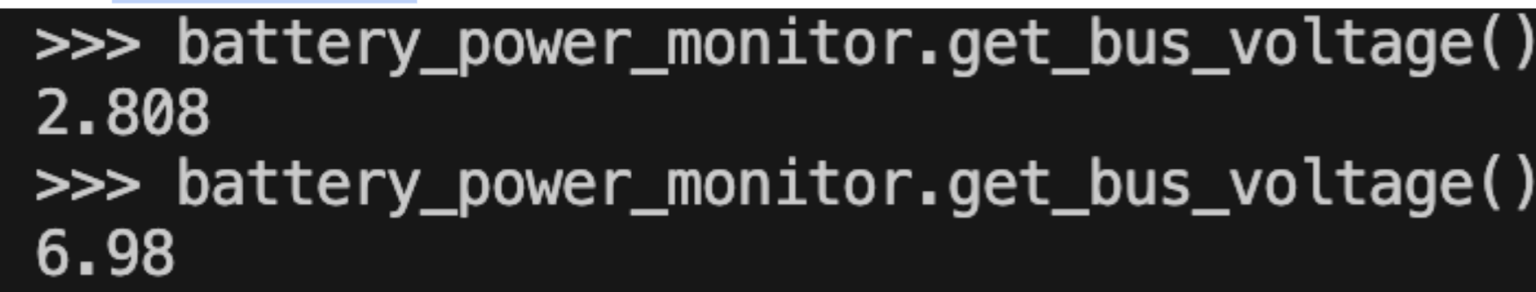
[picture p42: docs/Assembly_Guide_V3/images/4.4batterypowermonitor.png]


To test the power stops: While the batteries are plugged in, run `battery_power_monitor.get_bus_voltage()`. Press one of the power stops. Wait a few seconds and run `battery_power_monitor.get_bus_voltage()` again. The voltage should be lower when the power stop is pressed, confirming that the power stops are functioning correctly.

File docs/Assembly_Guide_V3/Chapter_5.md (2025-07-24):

# Chapter 5: Antenna Board

## Cutting and Drilling the Antenna

**1.** Pull out the tape measure from a Milwaukee 6ft keychain measuring tape.

**2.** Cut the measuring tape into 180mm lengths using a pair of scissors and trim the lengths based on the desired radio frequency.

!!!Note 
The antenna lengths need to be **165mm** to broadcast in the 437.4MHz range. If you are interested in broadcasting in other frequencies, use a dipole antenna calculator to find out the proper element length for your desired frequency. Remember to divide the length in half, as the added lengths of the antennas should be the expected length 

*<p align="center">**Figure 5.1: Cut antennas*</p>
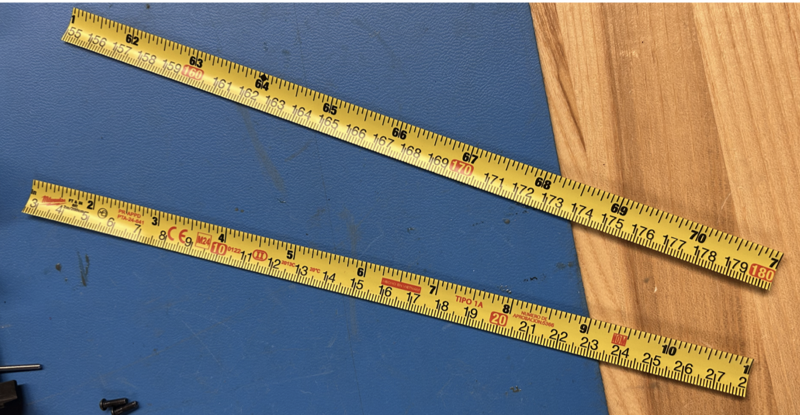
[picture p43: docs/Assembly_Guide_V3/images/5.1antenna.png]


**3.** Using a Dremel or sandpaper, sand off roughly ½-inch of the paint off the end of the measuring tape. Do the same to the opposite side of the measuring tape.

*<p align="center">**Figure 5.2: Sanded Antennas*</p>
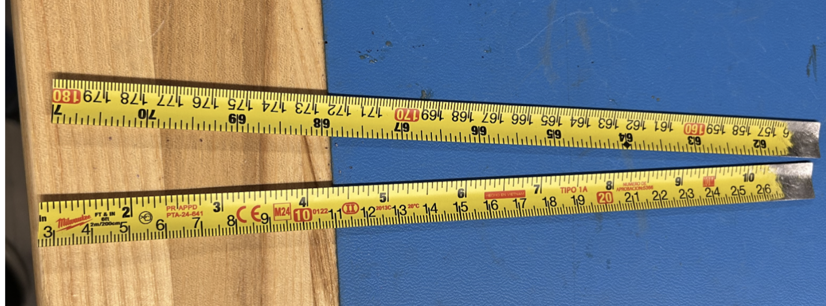
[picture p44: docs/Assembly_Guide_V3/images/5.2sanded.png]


**4.** Drill a hole through the exposed aluminum roughly 1-3mm away from the end of the length of measuring tape. Ensure you create a horizontal hole precisely in the center of the tape measure. Refer to Figure 5.1a.

*<p align="center">**Figure 5.3: Antennas with Hole**</p>*
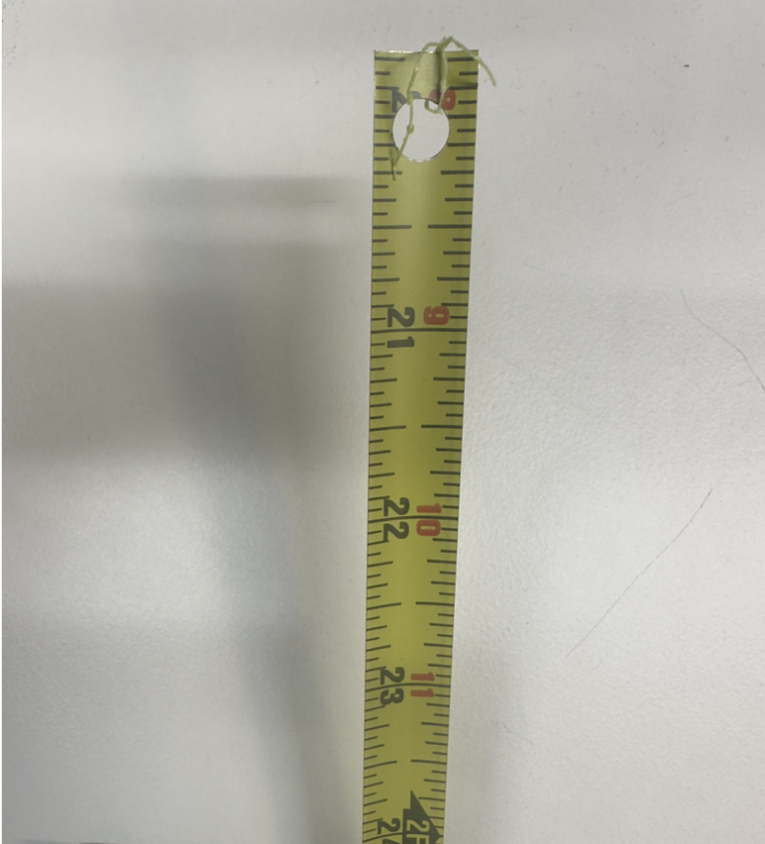
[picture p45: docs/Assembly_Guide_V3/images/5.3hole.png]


!!!TIP 
        Make sure to feed through the outward-facing side of the Top Cap so when the Top Cap is flipped over, the drilled hole of the antenna lines up with the open hole on the inward-facing side of the Top Cap

**5.** Remove this piece from the antenna board. Use a heat gun or unsolder with a soldering iron the plastic area pictured in Figure 5.4. Be very careful – you will need to put the heat gun or soldering iron at ~400°C to remove the small plastic piece. (Note: ignore the resistor in the picture, that will be added in the next step.)

*<p align="center">**Figure 5.4: Removing with Heat Gun**</p>*
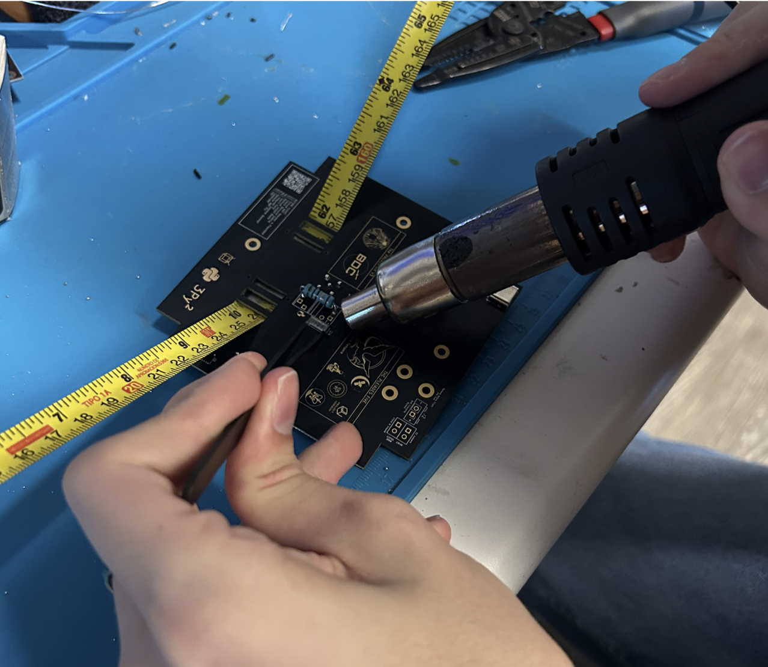
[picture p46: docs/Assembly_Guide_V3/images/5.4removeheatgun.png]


**6.** Grab a 10 ohm resistor and solder it to the location marked in Figure 5.4. It can be any resistor between 5-15 Ohms if you do not have a 10 Ohm resistor. This resistor is what the burnwire attaches to. When the burn starts, it will get really hot, burning the wire which will detach and deploy the antennas.

*<p align="center">**Figure 5.5: Added Resistor**</p>*
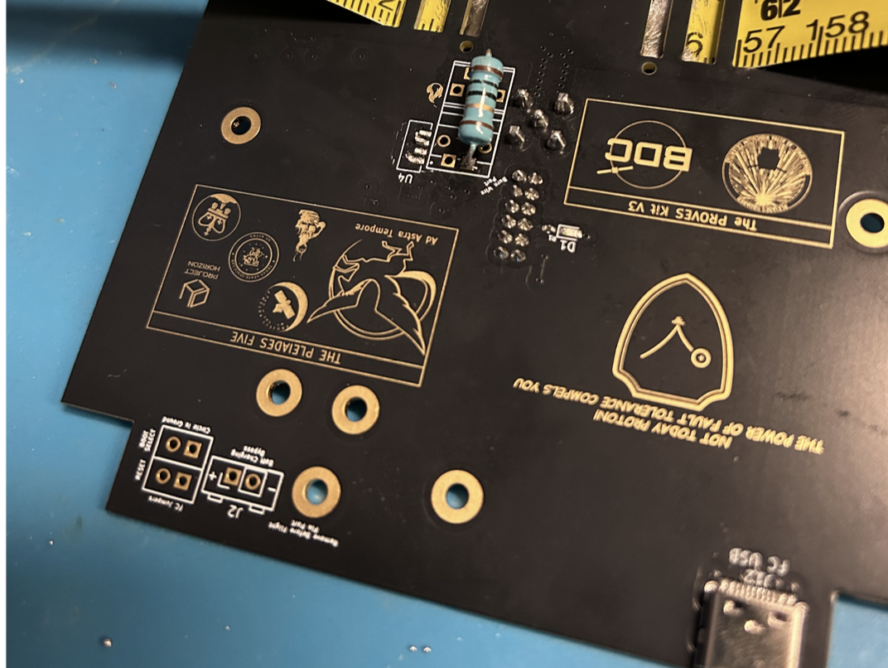
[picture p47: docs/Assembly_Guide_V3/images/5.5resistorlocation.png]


## Soldering the Antennas

**1.** Hold the antenna in place to solder it to the board. You can have someone hold it in place so it rests flush against the Top Cap or use a c-clamp to hold it as you are soldering. Refer to Figure 5.6 for how to feed the antenna through. 

*<p align="center">**Figure 5.6: Adding Flux to Antenna**</p>*
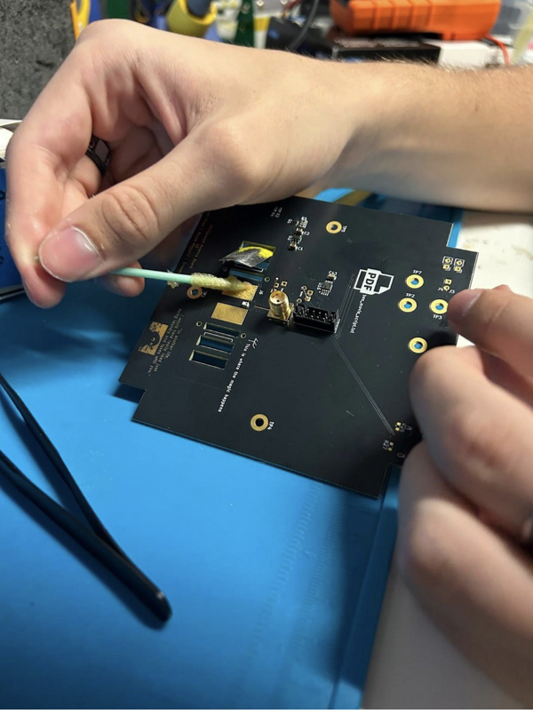
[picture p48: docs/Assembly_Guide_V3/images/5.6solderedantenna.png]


**2.** Solder as shown.

*<p align="center">**Figure 5.7: Soldered Antenna**</p>*
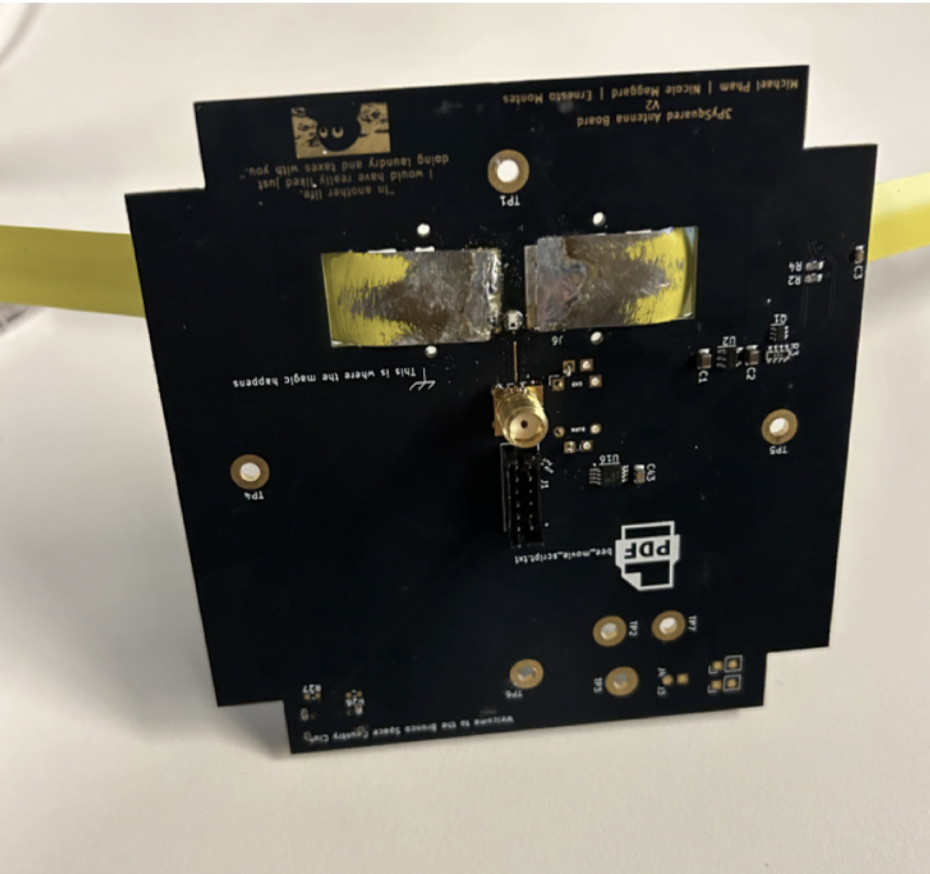
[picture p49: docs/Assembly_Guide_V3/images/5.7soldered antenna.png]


**3.** Wire the antenna board to the flight controller board.

*<p align="center">**Figure 5.8: Antenna Board Connected to Flight Controller Board**</p>*
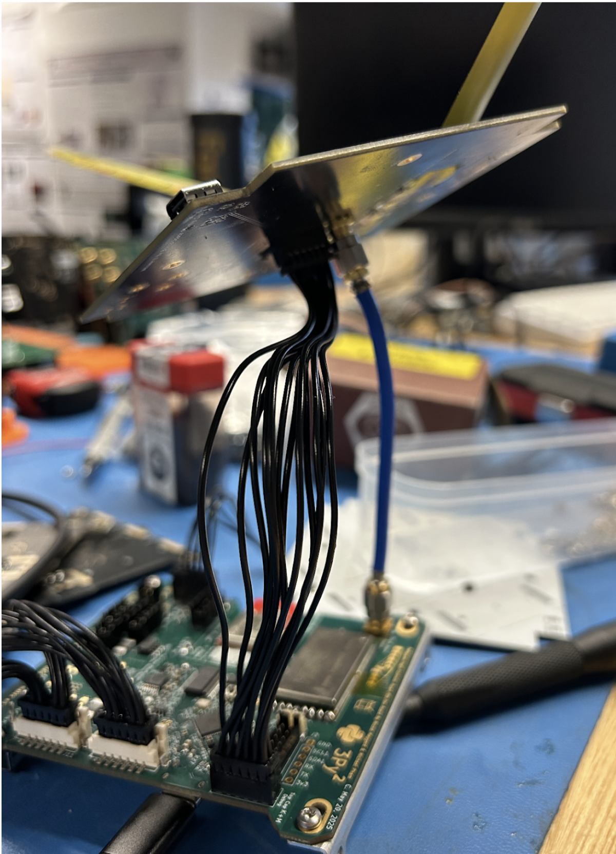
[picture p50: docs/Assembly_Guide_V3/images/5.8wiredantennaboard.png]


## Testing the Burnwire Circuit

**1.** Make sure you are connected to the battery board with the flight controller board and you have the power stops plugged in and connected to the flight controller board. We are going to test the burn wire! The burn wire allows the antenna to deploy. You would have a fishing line that collapses to the antenna tied to the resistor at the top of the flight controller board. The resistor gets really hot and eventually will burn the wire, which deploys the antenna. Run `antenna_deployment.burn()`. Burn optionally takes an argument for an amount of seconds, but watch out! A 10 Ohm resistor should not be powered for more than 15 seconds. You should feel the resistor getting warmer as shown in the before and after pictures taken of the resistor in the thermal camera.

*<p align="center">**Figure 5.9: Thermal Camera before Burn Called**</p>*
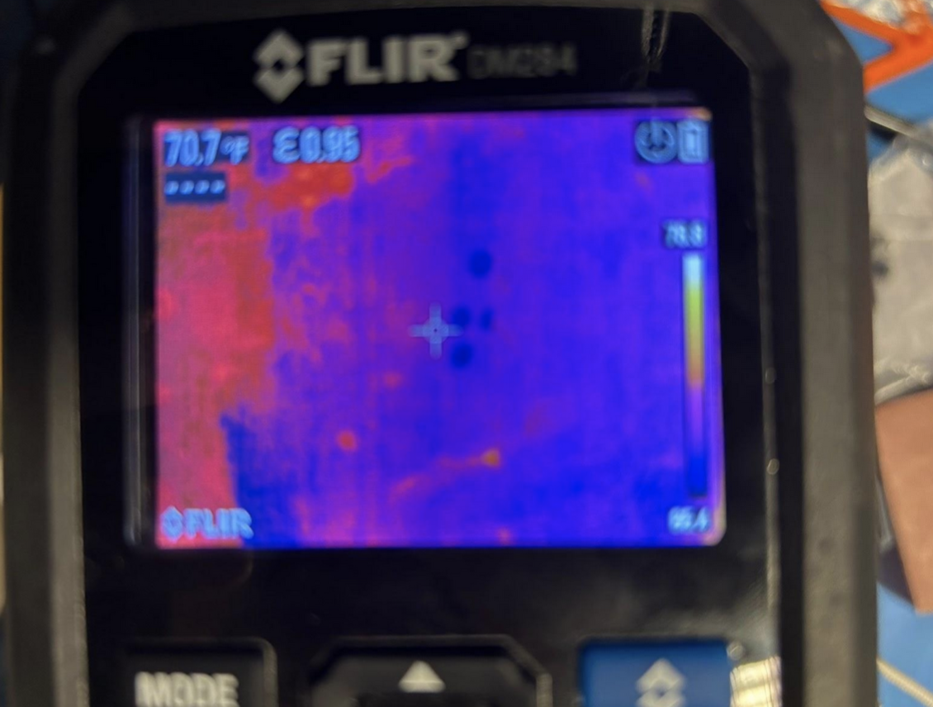
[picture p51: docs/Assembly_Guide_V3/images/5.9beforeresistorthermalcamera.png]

*<p align="center">**Figure 5.10: Thermal Camera after Burn Called**</p>*
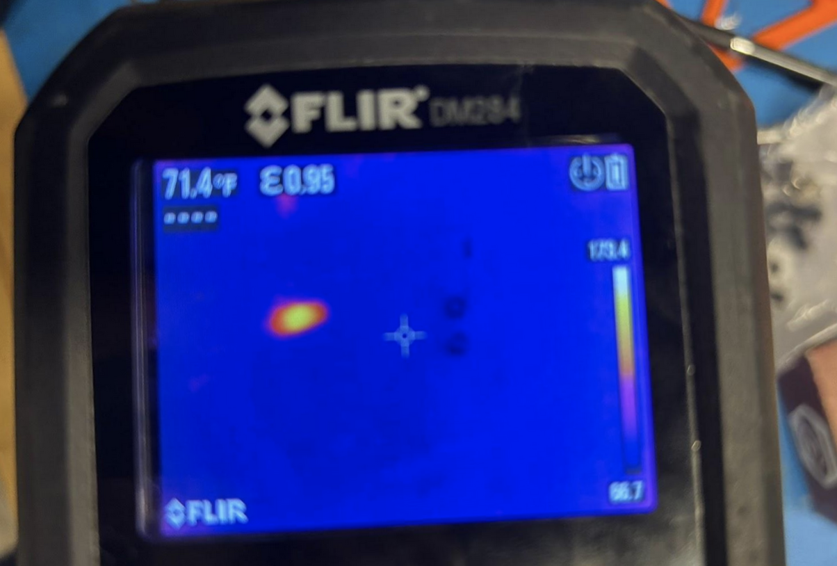
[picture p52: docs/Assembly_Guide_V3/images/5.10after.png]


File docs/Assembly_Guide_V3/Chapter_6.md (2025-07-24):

# Chapter 6: Integration Procedure

## Building the Cube
### Initial Structure Assembly
**1.** For this part of the integration, you will need two main “U” halves, four small L-shaped brackets, and stainless steel 5mm long M2.5 button head fasteners. Remember to remove all the tabs from the boards.

  *<p align="center">**Figure 6.1: Tabs to remove from all boards**</p>*
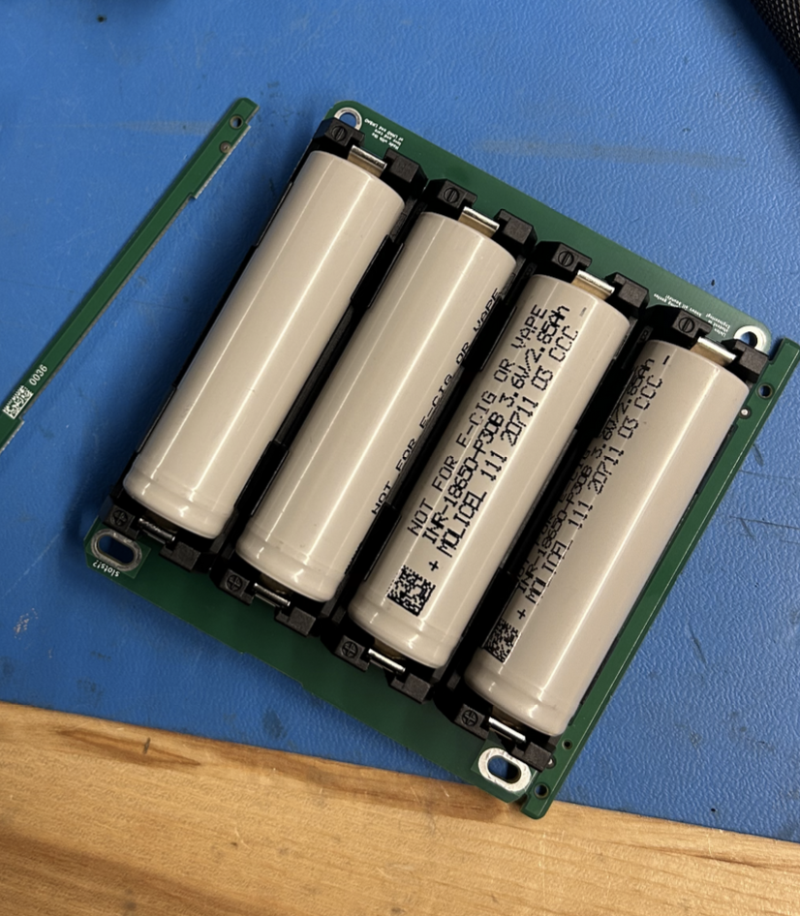
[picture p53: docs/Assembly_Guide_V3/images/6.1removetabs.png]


!!! note
      It is extremely important that the button head fasteners are used in this step and NOT the pan head fasteners for the L brackets, as this will allow the solar boards to fit on top of the fasteners.

**2.** Loosely attach the two halves together using the four L-brackets and 5mm fasteners as shown in Figure 6.2 below. Do not over-tighten, as we will “square up” the structure later using a jig.

*<p align="center">**Figure 6.2: Small Elbow Brackets placed on structure**</p>*
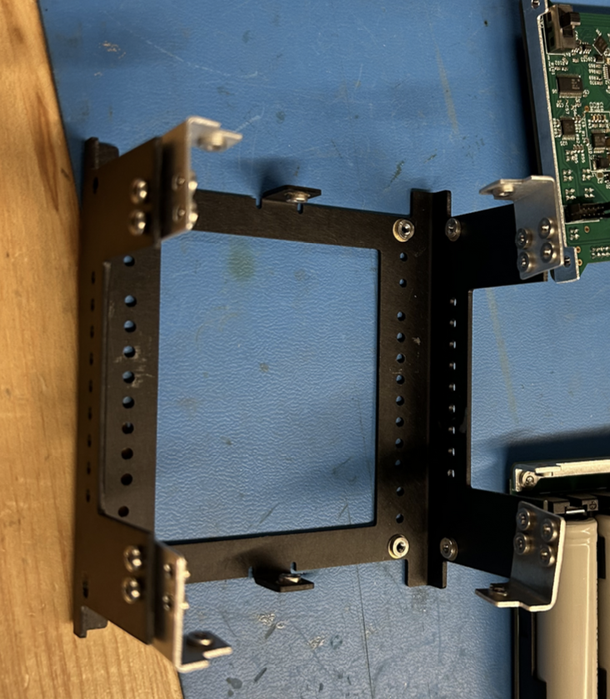
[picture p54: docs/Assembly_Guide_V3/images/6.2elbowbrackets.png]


!!! warning
    Make sure to ALWAYS screw in the fasteners horizontally when dealing with pre-installed pem-nuts.

**3.** If you happen to pop out one of the pem-nuts, secure the fasteners with locknuts, but be extra careful not to tighten them too much.

!!! warning
    TORQUE SPEC IS 0.59 N·m (5.22 in-lb), DO NOT EXCEED THIS ON M2.5 BOLTS/FASTENERS.

### Initial Bracket Mounting
**1.** Secure 2 battery board card brackets onto the board using M2.5x5mm pan head bolts as shown in Figure 6.3 below. Do the same for the flight controller board.

*<p align="center">**Figure 6.3: Attached board card brackets to Flight Controller Board and Battery Board**</p>*
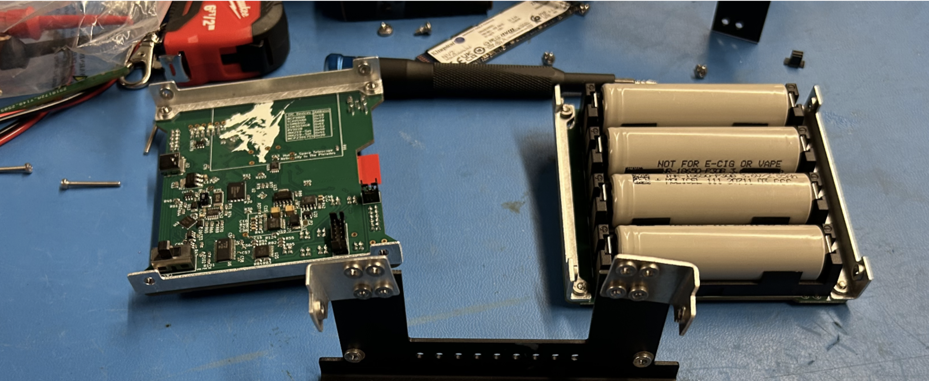
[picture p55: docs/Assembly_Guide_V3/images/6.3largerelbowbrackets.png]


**2.** Flight the flight controller board to the battery board. Then angle the board diagonally with attached brackets and insert into the internal volume of the main structure.

  *<p align="center">**Figure 6.4: Battery Board and Flight Controller Board on Satellite**</p>*
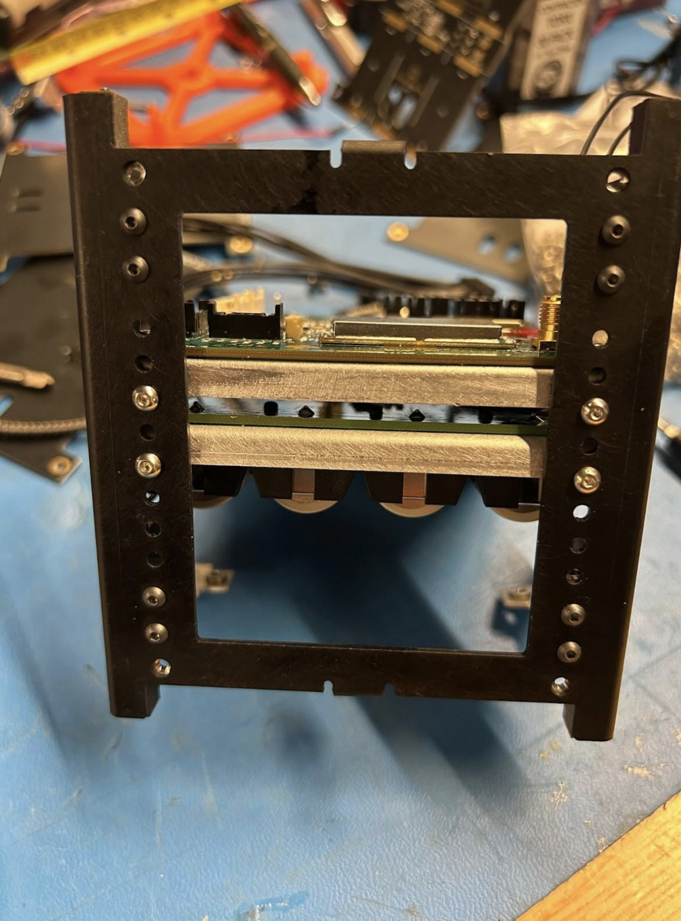
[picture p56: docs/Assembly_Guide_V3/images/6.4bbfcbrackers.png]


  *<p align="center">**Figure 6.5: Figure 6.4: Battery Board and Flight Controller Board on Satellite**</p>*
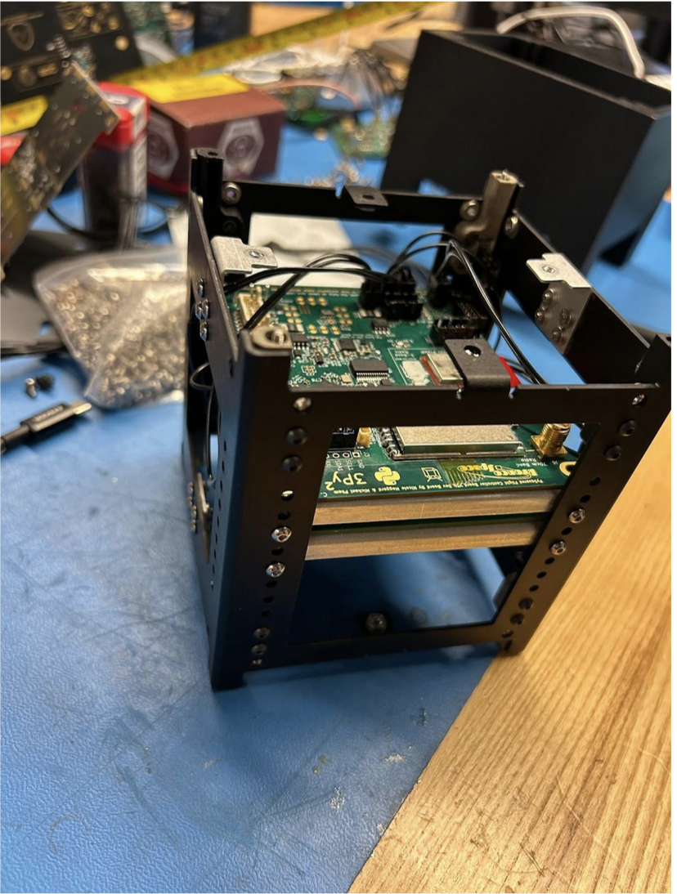
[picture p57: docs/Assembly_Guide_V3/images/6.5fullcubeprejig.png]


## Integrating Satellite Feet
### Installing Feet Assembly
**1.** Use M2.5x10mm pan head fasteners, and M2.5 locknuts to install the feet.Install the feet so the feet with the switches inside should be diagonal from one another. Use Blue Loctite if this is the final satellite.
**2.** To install the feet on the structure, place locknuts in the small openings of the feet as shown in Figure 6.6, with the nylon side of the locknut facing towards the interior of the satellite. Press downwards on the top of the feet while also pressing them up against the side of the structure. Remember to plug them into the flight controller board!

*<p align="center">**Figure 6.6: Feet Mounted on Satellite Half**</p>*
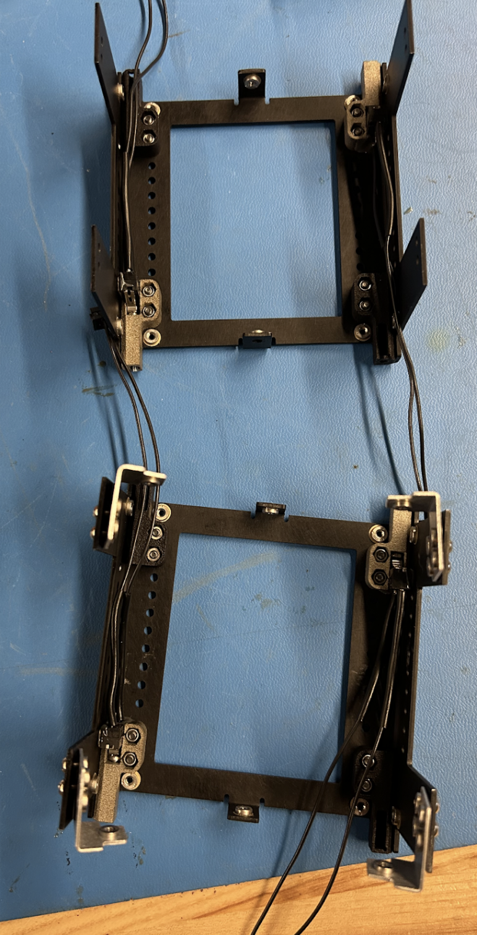
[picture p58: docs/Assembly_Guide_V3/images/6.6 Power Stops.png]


### Applying Thermocouple (Optional)
**1.** Apply space-rated glue to the thermocouple and place it on the side of one of the two middle batteries. Make sure that the metal part of the thermocouple is touching the battery casing.

### Applying Thermal Blanket (Optional)
**1.** Place strips of double-sided Kapton tape along the face of the batteries and press the thermal blanket down against the exposed tape.
**2.** Fold the ends back against the outer-facing side of the thermal blanket.

## Squaring the Satellite
### It’s Jig Time!
**1.** Place the structure into the jig as shown in figure 8.11. Slide it back and forth multiple times through the jig to square up the structure.

!!! note
    If you cannot fit the satellite into the jig, loosen the fasteners on the structure (not including the feet) and attempt to fit it again.

*<p align="center">**Figure 6.7: Satellite in Jig, able to be screwed at the top**</p>*
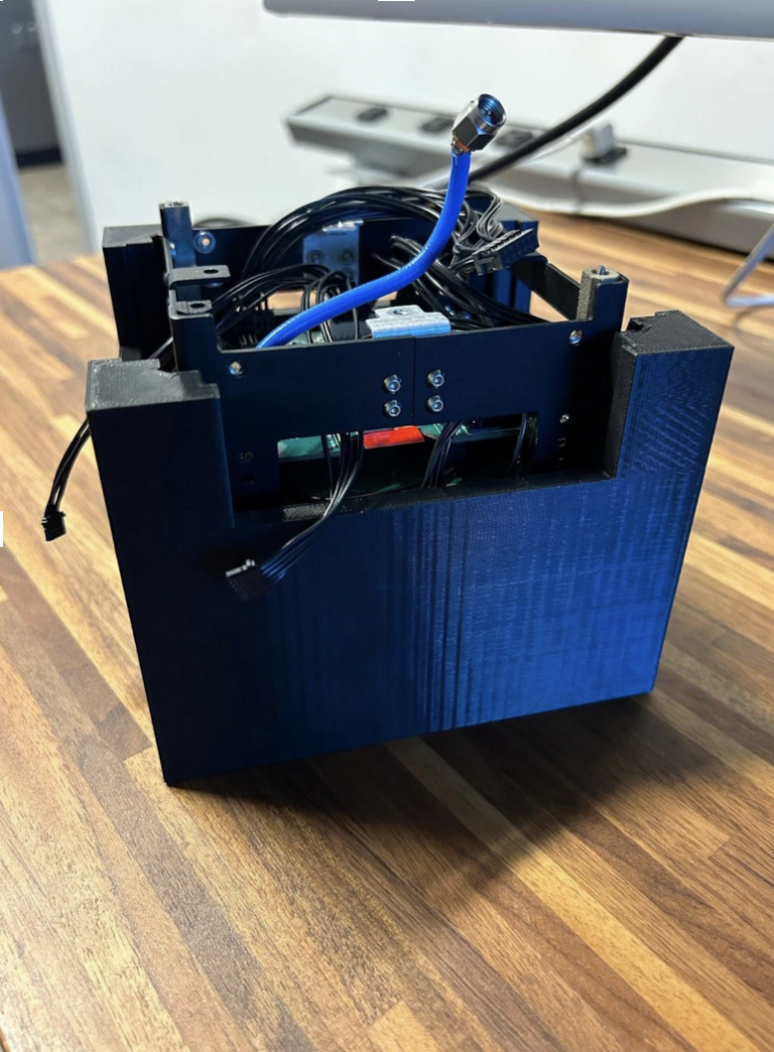
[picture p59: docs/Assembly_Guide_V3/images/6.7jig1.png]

*<p align="center">**Figure 6.8:Satellite in Jig, able to be screwed at the bottom**</p>*
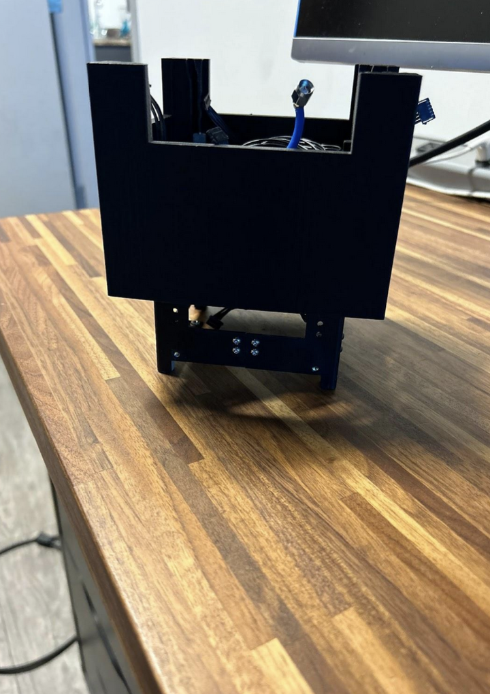
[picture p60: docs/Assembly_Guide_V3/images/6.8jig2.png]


**2.** If preparing for a launch, apply Loctite. Without taking the satellite out, unscrew fasteners one at a time and secure them by dipping them in Blue Loctite and placing them back in the structure. Be careful with the fasteners that are screwed into the small L brackets.

## Adding the Faces
**1.** Plug the faces into the flight controller board, including the Z-face and the antenna baord. Then screw them onto the faces of the cube. Wiring the Z-face before you fasten all the faces will make it easier to plug the Z-face in.
*<p align="center">**Figure 6.9: Solar Faces being added**</p>*
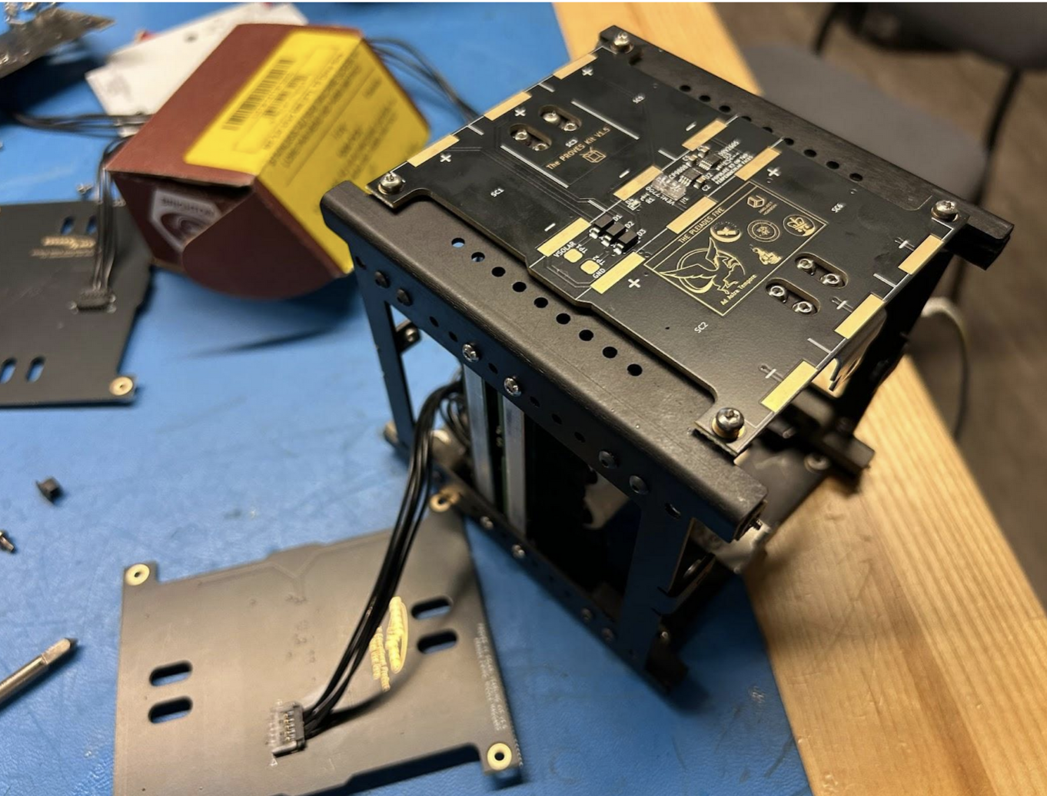
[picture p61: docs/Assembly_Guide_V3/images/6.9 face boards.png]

*<p align="center">**Figure 6.10: Z-Board being added**</p>*
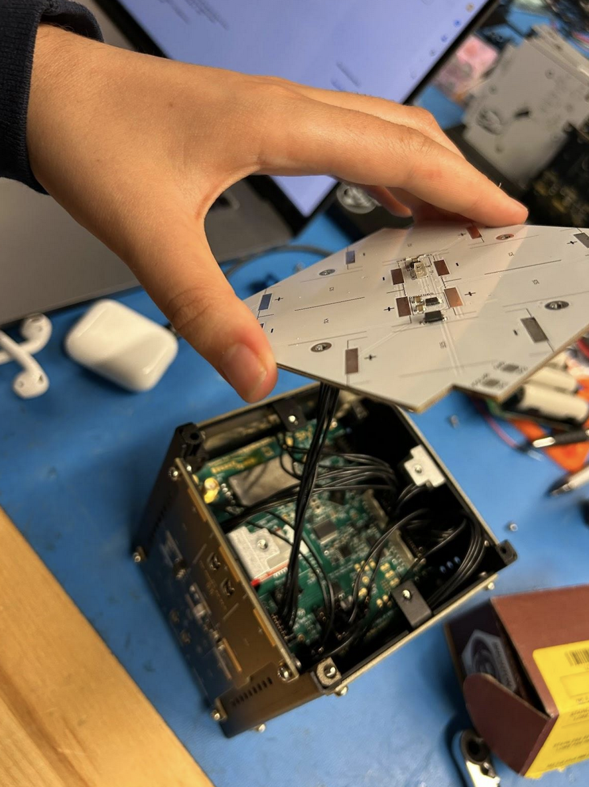
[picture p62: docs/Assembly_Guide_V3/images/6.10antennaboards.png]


!!! note
    You will have to remove one of the faces to program the cubesat as of now the antenna board USB-C doesn’t work. This should be in a later update.

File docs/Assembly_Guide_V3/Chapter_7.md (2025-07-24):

# Chapter 7: Final Check and Tests

## Final Check for Electronics
The final check for the electronics in the integration process involves running the same flat sat test code to ensure everything is communicating with each other when stacked in the satellite. For guidance on how to do these tests, refer to the [quick start guide](proves_quick_start.md), particularly how to use Tabby.

A fully assembled structure is required for this test:

**1.** Plug in the Micro USB cable.

**2.** Check Switch States
    - Make sure the feet switches and RFB Switch are not depressed. The satellite should be on before continuing (this can be verified by probing the 3.3V pin on the top of the flight computer).

## One Final Jig Test
It is important that the satellite is as square as possible so that it will properly fit into its deployer. Just as before, slide the satellite through the jig.

## Vibration Test
To qualify for space, the satellite will need to complete a random vibration test, so that it may ride on the rocket. Check with your flight provider for more information about vibration testing.

## Long Range Communications Test
To ensure the satellite is operating properly, it is important to see if the satellite can be heard from distances greater than 50km.

## Thermal Vacuum Chamber Test
To obtain an accurate idea of how the satellite will perform in space, the satellite should be exposed to extreme temperature shifts and vacuum environments.

## Congratulations!
You have just completed the integration of your satellite!

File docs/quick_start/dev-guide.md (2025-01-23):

# Development Guide
Welcome to the development guide for our project! This guide will help you set up your development environment and get you started with contributing to the repository.

## OS Specific Guides
We suggest you get started with the development guide for your operating system:

- [Windows](dev-guides/dev-guide-windows.md)
- [MacOS](dev-guides/dev-guide-macos.md)
- [Linux](dev-guides/dev-guide-linux.md)

Once you have your development environment set up, you should be able to run the following command to finish the setup:
```sh
make
```

## Manually testing code on the board
We are working on improving our automated testing but right now the best way to test your code is to run it on the board. We have provided the following command to make it easy to install code on the board:
```sh
make install BOARD_MOUNT_POINT=/PATH_TO_YOUR_BOARD
```

There is more information in the OS specific guides on how to find your board's mount point.

To see the output of your code you can connect to the board using the serial console. You can find more information on how to do that in the OS specific guides.

### Notes on Serial Console
If all you see is a blank screen when you connect to the serial console, try pressing `CTRL+C` to see if you can get a prompt. If that doesn't work, try pressing `CTRL+D` to reset the board.

## Continuous Integration (CI)
This repo has a continuous integration system using Github Actions. Anytime you push code to the repo, it will run a series of tests. If you see a failure in the CI, you can click on the details to see what went wrong.

### Common Build Failures
Here are some common build failures you might see and how to fix them:

#### Lint Failure
Everytime you make a change in git, it's called a commit. We have a tool called a pre-commit hook that will run before you make each commit to ensure your code is safe and formatted correctly. If you experience a lint failure you can run the following to fix it for you or tell you what's wrong.
```sh
make fmt
```

#### Test Failure
To ensure our code works as we expect we use automated testing. If you're seeing a testing failure in your build, you can see what's wrong by running those tests yourself with:
```sh
make test
```

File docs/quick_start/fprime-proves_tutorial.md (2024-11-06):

# Getting Started with fprime-proves
[Check Out the GitHub Repo](https://github.com/proveskit/fprime-proves)

!!! tip "From the F' Documentation"

    F´ (or F Prime) is a software framework for the rapid development and deployment of embedded systems and spaceflight applications. Originally developed at NASA’s Jet Propulsion Laboratory, F´ is open-source software that has been successfully deployed for several space applications. It has been used for but is not limited to, CubeSats, SmallSats, instruments, and deployables.

    [Learn More Here](https://nasa.github.io/fprime/)

In order to improve the reliability of the flight software flown on the PROVES Kit, we have been seeking to adopt the F' (F Prime) flight software framework developed by NASA JPL. This page takes you through a quick tutorial on how to setup an enviroment for developing with F' on the PROVES Kit and a tailored walkthrough of creating your first LED Blinker Component!

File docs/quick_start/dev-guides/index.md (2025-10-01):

# Development Guide
Welcome to the development guide for our project! This guide will help you set up your development environment and get you started with contributing to the repository.

!!! warning
    This developer guide is out of date. It still works, but check out the latest [at this link](proveskit.github.io/pysquared/).

#### CircuitPython
If this is your first time using CircuitPython, it is highly recommended that you check out Adafruit's [Welcome to CircuitPython](https://learn.adafruit.com/welcome-to-circuitpython/overview) to help you get started!

## OS Specific Setup Guides
We suggest you get started with the development guide for your operating system:

- [Windows Setup](\dev-guide-windows.md)
- [MacOS Setup](\dev-guide-macos.md)
- [Linux Setup](\dev-guide-linux.md)

Once you have your development environment set up, you should be able to run the following command to finish the setup:
```sh
make
```

## Manually testing code on a board
We are working on improving our automated testing but right now the best way to test your code is to run it on the board.

Your board must be connected to your computer, the correct board repository cloned, and you must have installed the latest CircuitPython Firmware.

Firmware can be installed by placing the board in Bootloader mode (by pressing both of the buttons simultaneously) and running the following command:
```sh
make install-firmware
```

In the board repository, you can run the following command to install code on the board:
```sh
make install BOARD_MOUNT_POINT=/PATH_TO_YOUR_BOARD
```

If you need to install a specific version of the `pysquared` library, you can do so by running:
```sh
PYSQUARED_VERSION=VERSION/BRANCH make install BOARD_MOUNT_POINT=/PATH_TO_YOUR_BOARD
```

There is more information in the OS specific guides on how to find your board's mount point.

To see the output of your code you can connect to the board using the serial console. You can find more information on how to do that in the OS specific guides.

### Notes on Serial Console
If all you see is a blank screen when you connect to the serial console, try pressing `CTRL+C` to see if you can get a prompt. If that doesn't work, try pressing `CTRL+D` to reset the board.

!!! bug "Known Issue for V5a+ Flight Controller Boards and Serial Consoles"

    Due to using an unstable build of CircuitPython for RP2350 based boards, when PROVES Kit software is installed on these boards and running automatically on boot you have a limited window to connect to the board with a serial console before the USB device is deactivated.

    Learn more in the following GitHub Issue:
    [[BUG] Use of PySquared safe_sleep Disables USB Connections #4](https://github.com/proveskit/CircuitPython_RP2350_v5a/issues/4)

### Using `reply.py` For Quick Validation and Debugging
One of the really nice things about CircuitPython is the presence of the Read Print Evaluate Loop or REPL. This feature allows you to use the CircuitPython interpreter in real time, typing arbitrary code into the console and seeing the output without having to go through a compiler on your dev machine. You are prompted with the option of entering the REPL when code is interupted with ++ctrl+c++ and the contents of `reply.py` will run automagically to setup any desired board support software that you may want to use.

Check out the following guides for how to use `repl.py` for quick testing and debugging of new and existing hardware:

- [FlatSat Function Testing Using the REPL](\dev-guide-repl-function-tests.md)
- [Testing a New Device Using the REPL](\dev-guide-repl-new-device-test.md)

## Continuous Integration (CI)
This repo has a continuous integration system using Github Actions. Anytime you push code to the repo, it will run a series of tests. If you see a failure in the CI, you can click on the details to see what went wrong.

### Common Build Failures
Here are some common build failures you might see and how to fix them:

#### Lint Failure
Everytime you make a change in git, it's called a commit. We have a tool called a pre-commit hook that will run before you make each commit to ensure your code is safe and formatted correctly. If you experience a lint failure you can run the following to fix it for you or tell you what's wrong.
```sh
make fmt
```

#### Test Failure
To ensure our code works as we expect we use automated testing. If you're seeing a testing failure in your build, you can see what's wrong by running those tests yourself with:
```sh
make test
```

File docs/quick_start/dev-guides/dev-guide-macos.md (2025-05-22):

# Development Guide for MacOS

## Setup

To get started with development on MacOS, follow these steps:

1. **Install Xcode Command Line Tools**: These tools are necessary for compiling and building software.
    ```sh
    xcode-select --install
    ```
1. **Install Homebrew**: Homebrew is a package manager for MacOS. Follow the instructions on [brew.sh](https://brew.sh/) to install it.
1. **Install Required Packages**: Open a terminal and run the following command to install required packages:
    ```sh
    brew install screen
    ```

If you haven't already, use a terminal to clone the repository for the board that you are trying to install code to.

=== "Flight Controller Board V4x"

    ```sh
    git clone https://github.com/proveskit/CircuitPython_RP2040_v4.git
    ```

=== "Flight Controller Board V5a"

    ```sh
    git clone https://github.com/proveskit/CircuitPython_RP2350_v5a.git
    ```

Once it is cloned, you should now be able to run the `make` command in the root of the repo to get started. This command will automagically complete the rest of the developer enviroment setup!

### A note on `make install`
`make install` is a command that can be used to quickly install the code you're working on onto the board. On Mac, you can find the location of your mount by looking for a mount named `PYSQUARED` in your `/Volumes` directory
```sh
ls -lah /Volumes | grep PYSQUARED
...
drwx------@  1 nate  staff    16K Jan  9 08:09 PYSQUARED/
```

For example, if the board is mounted at `/Volumes/PYSQUARED/` then your install command will look like:
```sh
make install BOARD_MOUNT_POINT=/Volumes/PYSQUARED/
```

## Accessing the Serial Console
To see streaming logs and use the on-board repl you must access the Circuit Python serial console. Accessing the serial console starts with finding the tty port for the board. The easiest way to do that is by plugging in your board and running:
```sh
ls -lah /dev
```
Look for the file that was created around the same time that you plugged in the board. For Mac users the port typically looks like `/dev/tty.usbmodem101`. You can then connect to the board using the `screen` command:
```sh
screen /dev/tty.usbmodem101
```

For more information visit the [Circuit Python Serial Console documentation](https://learn.adafruit.com/welcome-to-circuitpython/advanced-serial-console-on-mac-and-linux).

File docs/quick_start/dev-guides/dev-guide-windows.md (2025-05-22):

# Development Guide for Windows
Welcome to the Windows Development Guide for our project! This guide will help you set up your development environment on a Windows machine and get you started with contributing to the repository.

Follow the instructions below for either a native Windows setup or using the Windows Subsystem for Linux (WSL).

## Native Windows Setup (Recommended)

To set up your development environment on Windows, follow these steps:

1. **Install Git**: Download and install Git from [git-scm.com](https://git-scm.com/downloads). Make sure to also install the Git Bash terminal during the setup process.
1. **Install Putty or Tabby**: Download and install Putty from [putty.org](https://putty.org/). Download and install Tabby from [tabby.sh](https://tabby.sh).
1. **Install Chocolatey**: Chocolatey is a package manager for Windows. Follow the instructions on [chocolatey.org](https://chocolatey.org/install) to install it.
1. **Install Required Packages**: Open a command prompt or Git Bash terminal and run the following command to install required packages:
    ```sh
    choco install make rsync zip
    ```

If you haven't already, using the Git Bash terminal clone the repository for the board that you are trying to install code to.

=== "Flight Controller Board V4x"

    ```sh
    git clone https://github.com/proveskit/CircuitPython_RP2040_v4.git
    ```

=== "Flight Controller Board V5a"

    ```sh
    git clone https://github.com/proveskit/CircuitPython_RP2350_v5a.git
    ```

Once it is cloned, you should now be able to run the `make` command in the root of the repo to get started. This command will automagically complete the rest of the developer enviroment setup!

### A note on `make install`

`make install` is a command that can be used to quickly install the code you're working on onto the board. In Git Bash your mount point will be the letter of the drive location in windows. For example, if the board is mounted at `D:\` then your install command will look like:
```sh
make install BOARD_MOUNT_POINT=/d/
```

## WSL Setup
Windows Subsystem for Linux (WSL) is a nice way to have a POSIX compatible workspace on your machine, the downside is a cumbersome USB [connecting][connect-usb] and [mounting][mount-disk] process that needs to be performed every time you reconnect the Satellite hardware to your computer.

1. Download Ubuntu for WSL:
    ```sh
    wsl --install
    ```
1. Run WSL:
    ```sh
    wsl
    ```
1. If you have Satellite hardware, [connect][connect-usb] and [mount][mount-disk] it in WSL.
1. Continue with our [Linux Development Guide](docs/dev-guide-linux.md).

### A note on `make install`

`make install` is a command that can be used to quickly install the code you're working on onto the board. In WSL your mount point will be the letter of the drive location in windows. For example, if the board is mounted at `D:\` then you must first mount the disk in WSL:
```sh
mkdir /mnt/d
sudo mount -t drvfs D: /mnt/d
```

And your install command will look like:
```sh
make install BOARD_MOUNT_POINT=/mnt/d/
```

## Accessing the Serial Console
To see streaming logs and use the on-board repl you must access the Circuit Python serial console. For information on how to access the serial console, visit the [Circuit Python Serial Console documentation](https://learn.adafruit.com/welcome-to-circuitpython/advanced-serial-console-on-windows).

[connect-usb]: https://learn.microsoft.com/en-us/windows/wsl/connect-usb "How to Connect USB to WSL"
[mount-disk]: https://learn.microsoft.com/en-us/windows/wsl/wsl2-mount-disk "How to Mount a Disk to WSL"

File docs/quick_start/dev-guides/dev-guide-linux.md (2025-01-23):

# Development Guide for Linux

## Setup

To set up your development environment on Linux, follow these steps:

1. Update your package list and install the necessary packages:
    ```sh
    sudo apt update && sudo apt install make python3.12-venv screen zip
    ```

You should now be able to run the `make` command in the root of the repo to get started.

### A note on `make install`
`make install` is a command that can be used to quickly install the code you're working on onto the board. On linux you can use the `findmnt` command to locate your board's mount point.
```sh
findmnt
...
├─/media/username/SOME-VALUE /dev/sdb1 vfat rw,nosuid,nodev,relatime 0 0
```

For example, if the board is mounted at `/media/username/SOME-VALUE` then your install command will look like:
```sh
make install BOARD_MOUNT_POINT=/media/username/SOME-VALUE/
```

## Accessing the Serial Console
To see streaming logs and use the on-board repl you must access the Circuit Python serial console. Accessing the serial console starts with finding the tty port for the board. The easiest way to do that is by plugging in your board and running:
```sh
ls -lah /dev
```
Look for the file that was created around the same time that you plugged in the board. For Linux users the port typically looks like `/dev/ttyACM0`. You can then connect to the board using the `screen` command:
```sh
screen /dev/ttyACM0
```

For more information visit the [Circuit Python Serial Console documentation](https://learn.adafruit.com/welcome-to-circuitpython/advanced-serial-console-on-linux).

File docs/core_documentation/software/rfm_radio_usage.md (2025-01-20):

# How to Use the RFM9x With the PROVES Kit

The easiest way to test the radio on the PROVES Kit is to use the `radio_test.py` file that is located in the PROVES [tests_scripts repo](https://github.com/proveskit/test_scripts). Running `import radio_test` on a compatible Flight Controller Board will automagically get everything setup for a ping pong style radio test. 

The latest iteration of `radio_test.py` also has the option of automagically configuring the board it is deployed on to act as a client for sending commands to a remote node. 

# Understanding the Radio Config

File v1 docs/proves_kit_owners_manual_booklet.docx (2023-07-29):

# PROVES KIT

Owner’s Manual

The Spacecraft Company LLC

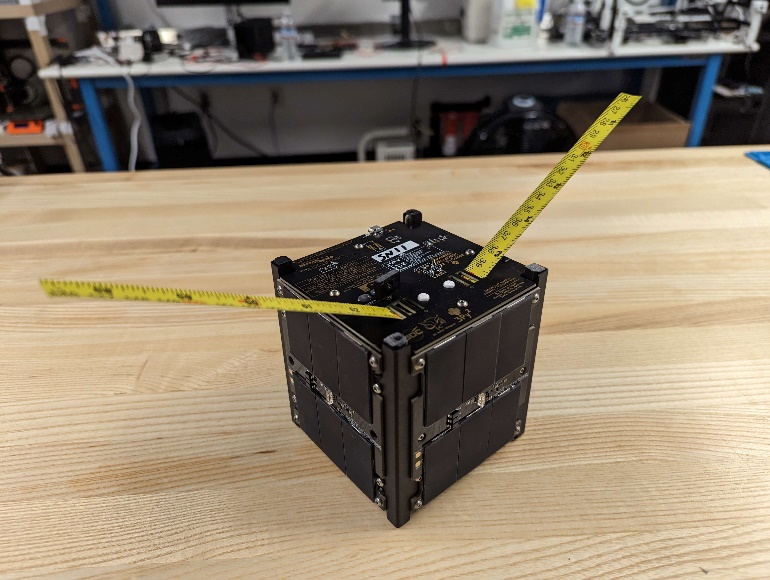
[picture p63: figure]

Produced: 7/23/2023

Table of Contents

# About your kit

Thank you for your interest in the PROVES KIT and congratulations if you are assembling one for educational or practical use! The PROVES KIT as of writing is a “1u” educational CubeSat kit that has been to space two times. The kit is centered around low cost off the shelf components that allow users to learn how to assemble and operate a real satellite that can go to space. Additionally, the design is completely open-source and updated periodically at www.github.com/proveskit. For specific space missions, users may desire to repurpose some designs to fit mission requirements.

## Main Kit Components

The satellite kit contains several printed circuit boards (PCBs), a sheet metal structure, and SLS 3d printed pieces.

### Flight Controller or Flight Computer

The Flight Controller (FC) is a custom PCB that maintains an RP2040 microcontroller, and HOPERF RFM98PW radio module. The FC is responsible for mission controls and communications. With an integrated tape measure antenna, the FC can support 430 and 915 MHz communications. (NOTE: the user is required to obtain the proper licensing prior /to utilizing the radio communications, and The Spacecraft Company LLC is in no way liable for violations that occur at the fault of the user)

### Electrical Power System

The Electrical Power System (EPS) is a custom PCB that houses the batteries, LT3652 MPPT Solar Charger, voltage regulators, INA219 power monitors, I2C multiplexer, and Power Driver for Solar Faces. The EPS is responsible for facilitating the charging of the batteries, as well as the voltage regulation and power monitoring. With the I2C multiplexer and Driver integrated into the EPS, the FC is able to take direct control of the Solar Faces from the EPS, obtain data, and delegate power.

### Solar Boards

The Solar Boards are separated into two separate categories: XY Faces and Z- Faces.

### Structure

The Structure is 0.063 inch thick Aluminum 5052-H32 sheet metal that has been laser cut, bent and anodized. PEM Nuts are pressed into the structure on mounting points where captive nuts won’t exist.

### Brackets

The PROVES KIT maintains two card brackets for mounting the EPS inside the structure. In addition, the kit maintains four L-Brackets for joining the structure together, and mounting the FC and Z- Solar Boards to the structure.

### Cabling

The PROVES KIT utilizes the MOLEX PicoLock Connectors and cables on all of the kit hardware. These connectors and cables ensure solid connections that won’t disconnect or fail during the mission. While these connectors can become costly, it is important to be able to maintain strong electrical connections once the satellite enters space.

### Feet

The PROVES KIT comes equipped with SLS 3d Printed feet for all 8 positions on the satellite. Two main foot designs are maintained for switch options to inhibit the satellite. The options are granted for two separate approaches. The embedded foot switch is utilized for applications where internal volume must be conserved, and the other foot switch is utilized for its comparative robustness to the prior mentioned foot, but this foot takes up more space.

### Remove Before Flight Switch

The PROVES KIT mounts the Remove Before Flight (RBF) Switch to the bottom of the FC. A pin can be inserted to ensure the switch gets depressed, and the satellite remains inhibited.

## Firmware

The FC maintains the RP2040 microcontroller, where custom CircuitPython firmware has been flashed. The RP2040 is also capable of running MicroPython and Arduino however these have not been tested in conjunction with the other satellite hardware, so CircuitPython remains the supported firmware for the PROVES KIT at the time of writing.

## Software

The FC software is available on the software GitHub repository at www.github.com/proveskit. Examples of full flight software can be found here but note that a radio license is required to operate the satellite communications prior to editing the lines of code that block transmissions from the radio.

# Maintenance

Your Satellite will require very little maintenance depending on the application. The batteries are of the most concern when it comes to long term storage of the satellite. To ensure proper function every time the satellite is pulled out for testing, the batteries should be charged to 8V using a power supply and charging through the direct charge port on the FC at least one every three months.

# Operations

## USB Operation

The PROVES KIT is equipped with a micro type B USB port on the top of the FC that allows for easy interfacing with the computer. A simple terminal software is needed to view the output of the satellite software. The recommended terminal software is Tabby Terminal, however other terminal software’s should be able to display the satellite output.

## Radio Operations

As stated before, a radio license will be required before operation of the radio. However, if you the user is licensed, then you may proceed to transmit radio signals from the satellite, and the LoRa signals could be heard on the corresponding frequency. This can ensure the satellite is transmitting all of the correct data without being plugged into a computer and can ensure good signal integrity from the satellite.

# Troubleshooting

The GitHub organization (www.github.com/proveskit) is a public organization and issues can be generated for any of the repositories. If any bugs occur with the hardware or software, please do not hesitate to raise an issue on the corresponding repository or email us a support@tsco.space.

# Obtaining a Serial Number

To obtain a serial number for a satellite put together by the end user, the end user will need to send an email with the following:

- An image of the completed satellite
- A screenshot from a terminal showing all hardware working properly. With the PROVES KIT Software, this would be the print of the hardware dictionary showing all hardware with a ‘TRUE’ attached.
- A screenshot showing data from all I2C sensors
- A screenshot showing a received packet on another device from the satellite

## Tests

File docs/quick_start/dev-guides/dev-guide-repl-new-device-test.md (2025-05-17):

# Testing a New Device Using the REPL
What if we have a new sensor that we want to introduce to the PROVES Kit and we want to just run some very rough and tumble testing to make sure it works at all.

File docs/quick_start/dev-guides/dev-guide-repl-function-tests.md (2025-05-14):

# Testing a FlatSat Functions Using the REPL
So, you just got all the parts for a PROVES Kit! What now?

!!! info "Guide Version Control"

    Version Number: V0 
    * Written By: Michael Pham
    * Published May 14, 2025
    * Estimated Time to Complete: 20 minutes
    
    Dev Enviroment Used:
    * MacOS
    * Tabby Terminal Software
    * `pysquared v2.0.0-alpha-25w20`
    * Flight Controller Board V5a
    * XY Solar Panel V2

The good news is that it is easier than ever to get things running and code tested. This guide presumes that you have already setup a developer enviroment on your computer and have a built engineering unit or "FlatSat" wired up in front of you. That should look something like the attatched **Figure 1**.

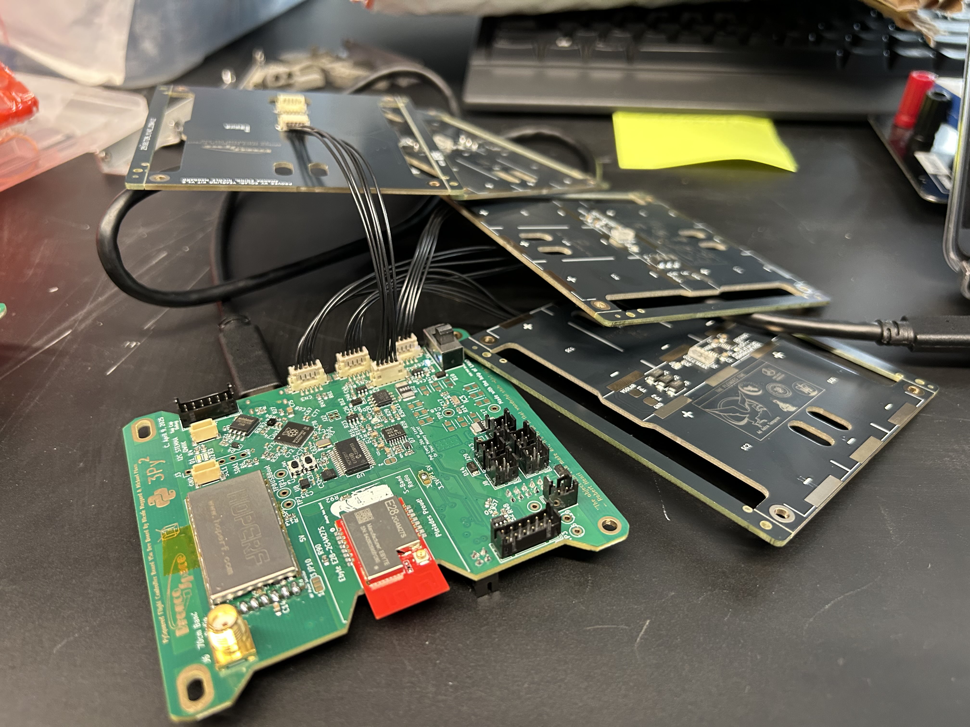
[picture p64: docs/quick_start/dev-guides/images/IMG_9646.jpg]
FlatSat

<p align="center">Figure 1: Example FlatSat From Columbia</p>

## Step 1: Connecting to the Flight Controller Board
There should just be a single USB-C for you to plug into with your computer. From here opening a serial terminal using your preferred software will get you hooked up with the board's CircuitPython Enviroment. The baud rate doesn't really matter just choose something bigger than 9600.

!!! bug "Time Sensitive Serial Connection with RP2350"

    If you are using a V5a+ board, you'll need to open this serial connection within about 13s of board power up. The reason for this is explained in the following GitHub issue:

    [[BUG] Use of PySquared safe_sleep Disables USB Connections #4](https://github.com/proveskit/CircuitPython_RP2350_v5a/issues/4)

Once you are connected to the Flight Controller Board try using ++ctrl+c++ to interrupt the code and then hit ++enter++ to go into the `REPL`.

??? note "No Big Logger Output?"

    Logs will appear by default in a `json` format when our CircuitPython Flight Software is installed. If you don't see logs appear make sure you have actually installed software onto the board using your computer's development terminal!

    === "Windows"

        ```sh
        make install BOARD_MOUNT_POINT=/d/
        ```
    
    === "MacOS"

        ```sh
        make install BOARD_MOUNT_POINT=/Volumes/PYSQUARED/
        ```
    
    === "Linux"

        ```sh
        make install BOARD_MOUNT_POINT=/media/username/SOME-VALUE/
        ```

## Step 2: Try Out Some Predefined REPL Functions!
You can read through the `reply.py` for the V5a Reference to see all of the implemented functions, but we will highlight the use of a few of the more interesting ones here.

### Sending a Radio Ping

!!! Warning "Proper Usage of Amateur Radio Bands"
    By default the radios assembled onto the PySquared Flight Controller Boards are designed to work within the amateur radio bands. To transmit legally in these bands you (or someone helping you) must hold a current Amateur Radio License. Within `config.json` there is an `is_licensed` field that automagically blocks transmissions without affirmation that you hold a proper license.

    If you wish to still test the radio system without a license, or licensed individual present, you can use attenuators or a dummy load to ensure that no unintended radio emissions are created.

Both radios on the V5a Flight Controller Board are setup in `repl.py` to use the same software radio protocol. As a result all you have to do to send a message is type into the `REPL` the following:

```py
# Use of Radio2 is safer because it has an built in antenna
radio2.send("Hello World!")
# If you have an antenna attatched feel free to use the UHF radio
radio.send("Hello World!")
```

If you have a nearby SDR tuned to the right frequency or another radio set to a receive loop you should see your ping appear!

### Power Cycling the Faces
If you have all of those solar panel faces hooked up to the flight controller board you can try using either of the following functions to turn them on or off. You should be able to see those fun LEDs cycle on and off with each command!

```py
all_faces_off()
# Pause a little bit to admire
all_faces_on()
```

### Getting Face Data
By default in `repl.py` the initialization of the TCA and all of the solar panel faces is disabled to avoid a barage of error messages when powering up the board without any solar panel boards attatched. Start by uncommenting it out in your dev enviroment and rerunning `make install`.

```py
###### Find and Uncomment This Line ########
all_faces = AllFaces(tca, logger)
```

Once that updated code is installed into the board you can now get a readout of all the sensors on the solar panel faces using the following.

```py
All_faces.face_test_all()
```

In the printout the first value in each grouping is the temperature and the second value is the light sensor readout. Try using a flashlight to see how the light sensor values change as you move across them!

### Collecting Data Using a Loop
One of the really fun things you can do with the `REPL` is writing loops to dynamically collect data. 

First we will want to import `time` this gives us access to `time.sleep()`.

```py
import time
```

Next let's try printing the imu data inside of a `while` loop at a 2hz (twice per second) polling rate.

```py
while True:
    time.sleep(0.5)
    print(imu.get_acceleration())
```

This should now print the accelerometer data from the IMU twice per second! Try tilting the board from side to side and seeing the values change.

??? tip "Indenting in the REPL"

    If this is your first time using the REPL, you can go to a new line without sending the command by using ++shift+enter++.

For a little more advanced readout you can print using an `f` string that takes the individual indices of the IMU output.

```py
while True:
    time.sleep(0.5)
    accel_data = imu.get_acceleration()
    print(f"X: {accel_data[0]}m/s^2 Y: {accel_data[1]}m/s^2 Z: {accel_data[2]}m/s^2")
```
Fun!

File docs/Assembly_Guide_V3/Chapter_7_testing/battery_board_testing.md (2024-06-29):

# Battery Board Testing

### Information about Healthy Batteries

| Voltage Range | Status |
|---|---|
| 3 - 3.2V | Danger Zone |
| 3.2 - 3.4V | Low |
| 3.4 - 3.7V | Normal |
| 3.7 - 4V | High |
| 4 - 4.2V | Danger Zone |

The cells may end up in the danger zone for one of two reasons:
- **Undervoltage:** Concern for the health of the battery but not a safety concern.
- **Overvoltage:** Concern for the health of the battery and the safety of the people around the battery. Overcharging can cause the battery to explode.

!!!Warning **CAUTION:** Before proceeding with this test, ensure the batteries you utilize all have a voltage of 3.4V and above and are balanced (each cell within +- 0.05V from each other).

The main objectives in testing the battery board are to verify that the battery protection network and voltage regulation are functioning properly. Follow these steps:

1. **Insert Batteries into the Holders**
    - Insert batteries into the battery holders on the bottom side of the board, starting on the right and moving towards the left. Follow the posted polarity on the board.

2. **Check Battery Connection**
    - Flip the board over and observe the various test points.
    - Use a voltmeter to test the pack voltage. Place the positive probe into the B+ test point and the negative probe into the B- test point. The voltage should be greater than 6V.
    - If the pack voltage is below 6V, follow troubleshooting steps:
        - If voltage is below 6V but not 0V, recharge the cells.
        - If voltage is at 0V, check battery polarity and solder joint connections.
        - Test voltages across each cell; replace any cell sitting at 0V.

3. **Battery Protection Check**
    - Test the pack voltage against ground. Place the positive probe into the B+ test point and the negative probe into the GND test point. The different voltage measurements should match.
    - If the voltage differs, check for overcharge or over discharge protections.

4. **Jump J18 for Power**
    - Jump J18 on the top side of the board with a jumper cable to bypass the feet switches and RBF switch.

5. **Voltage Regulation Test**
    - Test the 3.3V on the board. Place the positive probe into the 3.3V test point and the negative probe into the GND test point.
    - If 3.3V is not generated, troubleshoot by ensuring battery protection hasn't triggered and that the pack voltage is passing through.

6. **Functionality Test of Feet Switches and RBF Switch (Optional)**
    - Remove J18 jumper and connect the switches.
    - Test all points against GND, then depress the RBF switch and retest.
    - Replace switches if they do not function properly.

If everything checks out then its good to go!

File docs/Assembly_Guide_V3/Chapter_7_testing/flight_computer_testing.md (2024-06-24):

# Flight Computer Testing

The main goal of testing the Flight Computer is ensuring that the board receives power and that the board is loaded with the correct firmware. Follow these steps to test the Flight Computer:

1. **Jump J? on the Flight Computer**
    - Jump J? on the top side of the Flight Computer to allow the board to be supplied power from the USB.

2. **Plug in the Micro USB**
    - Plug in the Micro USB end into the Flight Computer board and plug the USB-A end into a computer.

3. **Check the LED Indicator**
    - Ensure the LED on the bottom side of the board is illuminated. If it is not, then the board is not powered. Check the following:
        1. Ensure that J? is being jumped.
        2. Check the solder joints on the USB connector and reflow the solder joints if necessary.

4. **Verify Disk Drive Recognition**
    - If the board is powered, the Computer should identify a new disk drive called PYSQUARED. If the computer does not recognize the device or shows up with a different drive name, follow these steps:
        1. If the drive shows up as RP1-RP2, then the firmware needs to be reflashed.
        2. If the device is not detected on the computer, reflow the solder joints of the Micro USB connector on the board.
        3. If the device is detected but not recognized, try reinstalling the device driver.
        4. If the device is detected and recognized as a “USB-DRIVE”, then the microcontroller is broken and the board should be replaced.

5. **Open a Terminal**
    - Open a terminal on the computer at the COM port of the Flight Computer (found using the device manager).

6. **Interrupt Running Software**
    - In case software is running on the board, press Ctrl + C to interrupt the code and press enter to enter the REPL.

7. **Import Board in REPL**
    - Once in the REPL, type “import board” and press enter.

8. **Check Pin and Bus Definitions**
    - Type “dir(board)” to bring up all of the pin and bus definitions in the firmware.

9. **Verify Board Operation**
    - If you get all of the definitions, then the Flight Computer board is operating normally. If there are errors or nothing appears, troubleshoot as follows:
        1. Ensure the correct COMS port is selected.
        2. Ensure any code is interrupted and that the REPL has been entered.
        3. Ensure there are no typos in the commands.

10. **Disconnect the Flight Computer**
    - Disconnect the Micro USB end from the Flight Computer and disconnect the Jumper at J?.&#8203;``【oaicite:0】``&#8203;

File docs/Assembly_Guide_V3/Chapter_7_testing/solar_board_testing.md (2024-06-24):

# Solar Board Testing

To test the solar panels on the satellite, a voltmeter is used to measure the voltage across all the cells. Each board that houses the six solar cells has two bare metal pads, one labeled VSOLAR and the other labeled GND. The testing steps are as follows:

1. Bring the Solar board into direct sunlight.
>**NOTE:** If direct sunlight is unavailable, a bright light from a car’s high beams may suffice for testing, but may return a lower-than-normal voltage reading and may leave the test results inconclusive.

2. Without placing a shadow on any of the cells, place the positive probe of the voltmeter on the VSOLAR pad and the negative probe on the GND pad.

3. Ensure the voltage being read is above 10V.
    - If the reading is 10V or above, the test is complete, and the cells on the solar board are functioning properly.
    - If the reading is significantly less than 10V, continue to the following steps for troubleshooting:
        a. Ensure cells are unobscured from sunlight.
        b. Ensure proper contact of probes to bare test pads.
        c. Testing the voltage across individual cells may become necessary:
            i. Identify the pads above and below each cell.
            ii. Place each probe on each pad.
            iii. If voltage reads close to 0 in direct sunlight, then the probe may not be in contact with the pad, or the cell is broken and the board must be replaced. 
        > NOTE: Replacing the cell may be possible but is not advised as re-exposing the other cells to the reflow oven temperatures may cause unintended damage.

4. Repeat steps 1 through 3 for each solar board.

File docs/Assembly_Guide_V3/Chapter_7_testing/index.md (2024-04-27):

# Chapter 7: Testing Procedures Overview

This overview provides links to various testing procedures outlined in Chapter 7. Each link leads to a detailed guide on how to perform each specific test.

## Testing Sections

- [Solar Board Testing](solar_board_testing.md)
- [Battery Board Testing](battery_board_testing.md)
- [Flight Controller Testing](flight_computer_testing.md)

Please click on the links above to navigate to the respective testing procedure.

---

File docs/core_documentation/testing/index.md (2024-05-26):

# PROVES Kit Testing

## Required CubeSat Testing

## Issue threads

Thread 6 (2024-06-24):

Broken Figure References in Assembly Guide V1.5

Mikefly123, 2024-06-24:
In Chapter 4 of the V1.5 Assembly Guide the figure references for Figures 4-4 through 4-8 are not appearing correctly.

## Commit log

2023-07-24 updating part list
    [kit_part_list.xlsx]
2023-07-29 Updated Documentation
    [jig.step]
2023-12-22 Updated Top Level Assembly Guide FIle
2024-01-24 Added more publications
    [PROVES RBF.stl]
2024-04-30 Landing Page Updates
2024-05-28 Added a FlatSat Dev Board Page
2024-05-29 File Restructure
    [kit_part_list.xlsx]
2024-05-29 Moved out the jig and rbf
    [PROVES RBF.stl, jig.step]
2024-06-01 Added photo of XY Solar Board
2024-06-12 Added button locations for internal fc
2024-06-12 Added picture of Battery Board
2024-06-14 assembly guide v2
2024-06-14 new title
    changed title from sample to chapter 3
2024-06-24 RBF switch update
2024-06-24 battery testing
2024-07-16 Updated FC Board Docs
2024-07-19 Updated FC Board
2024-07-19 Added Schematic Pictures to BB Docs
2024-09-13 Added details about the Burn Wire
2024-10-14 Added BB Schematic Pictures
2024-11-05 Created batt-pico-sdk changelog
2025-01-26 Added Rachel's Schematics
2025-02-09 Update Prime Board Devlog
2025-02-11 Version line
    Updated current version
2025-07-24 assembly guide v3 inital commit
2026-10-31 Add kit viewer model build and parts check tools
    build_kit_glb.mjs turns a raw Onshape assembly glTF export into a
    compact kit.glb: one node per top-level instance (named as in Onshape),
    simplified and meshopt-compressed. check_kit_parts.mjs fails when
    parts.json names a node the model lacks or two parts claim one node.
2026-10-31 Polish kit viewer motion and disclosure after design review
    Hover peeks a part with a glow and name tooltip; click shows details
    beside the part; a second click or double-click zooms to it. Selection
    dims everything else to one neutral ghost with a short fade instead of
    tinting the part. Camera flights ease out, scale with distance, and
    cancel when you grab the model. The explode slider no longer moves the
    camera, and the Explode label animates it open or shut.
    The parts list is grouped with short labels, the details card clamps to
    two lines behind More, and phones get one bottom sheet that swaps
    between the list and the details. When embedded, the viewer follows the
    docs site palette toggl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
2026-11-01 docs(kit-viewer): describe the payload slot
2026-11-06 Recolor the kit viewer model to match the flight hardware
    palette.mjs holds one table of materials taken from photos of the real
    satellite, and the rules mapping raw CAD colors, leaf names and sizes to
    them. The build now produces one primitive per palette material, and
    fails on any CAD color with no rule. It also lays out UVs per solar cell,
    so viewer.js can draw silver borders and grid lines on the cells without
    storing a texture in kit.glb. The room lighting is lowered and the hover
    glow raised so black parts keep their form and still show the glow.
2026-11-06 Give the kit viewer 44px touch targets on touch screens
    Toolbar buttons were 31px tall, list rows 30px and the close button
    32px. On coarse pointers they are now at least 44px.
2026-11-07 Add a step-by-step build guide to the kit viewer
    The Build button walks through the recommended 1U build order in 11
    steps. Each step shows only the parts installed so far, flies the new
    parts in from their exploded positions, dims the rest, frames the
    camera, and gives the instructions. Steps live in guide.json and
    deep-link with ?step=N.
    parts.json splits the battery board's card brackets into their own
    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
2026-11-07 Mount the battery card brackets on the component side
    The Electra assembly put the battery board's card brackets on the cell
    side, where they do not fit the frame. cad_fixes.mjs flips each one
    180 degrees about X through the PCB mid-plane. build_kit_glb.mjs
    applies the fix to fresh Onshape exports, and apply_cad_fixes.mjs
    applied it to the committed kit.glb by rewriting only node transforms.
    Claude-Session: https://claude.ai/code/session_013cP1i2CzWkKUqXCBpVkMWa
2026-11-08 Add a way back to the docs from the full-screen kit viewer
    Opened full screen, the viewer had no link back to the docs, and the
    docs button opened it in a new tab with no back history. On a phone
    there was no way out.
    The toolbar now starts with a back link to the kit page when the viewer
    is not embedded (a chevron on phones, "Docs" on wider screens), and the
    full-screen button opens in the same tab so the browser's back works.
    The phone toolbar's slider flexes and its padding shrinks so the extra
    button fits at 375 px wide.
2026-11-09 docs: rewrite the quick start guide around four onboarding paths
    Replace the CircuitPython-era quick start with a path chooser (software only,
    flight controller board, radio stick, full kit) plus shared pages for the
    development environment, the ground station, and troubleshooting. Move the old
    page to legacy_circuitpython_quick_start.md. Findings from a blind run of the
    pages on the lab Pi 500 are folded in.
    Claude-Session: https://claude.ai/code/session_013cP1hzx6YduJEe8FFC5MRX
2026-11-09 docs: fix two assembly guide links to the quick start
    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
2026-11-09 docs: radio stick path loads the Ground Radio Controller software
    The stick ships with no software. Replace the CircuitPython passthrough
    steps with building ground-radio-controller for proves_radio_stick_v2,
    applying the SX126x wake-up patch, flashing zephyr.uf2, and pointing the
    GDS at the stick's data port by its /dev/serial/by-id name.
    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
2026-11-09 docs: restructure reference pages into tables and diagrams
    Glossary, parts lists, jumper settings, errata, serial numbers,
    version explainer, flight heritage, troubleshooting and the solar
    cell comparison move from stacked subheadings and definition lists
    into datasheet style tables. Mermaid flowcharts show the quick start
    path sequence, the TLV1704 watchdog signal chain and the structure
    part tree. No technical facts change.
2026-11-09 docs: correct L-bracket count, Orpheus launch, and the payload and mechanism cards
    Michael confirmed four L-brackets, NC foot switches, and the December
    2024 Bandwagon-2 launch of Pleiades - Orpheus. The Camera Payload and
    Mechanisms cards on the kit elements page carried copy-pasted structure
    text and now describe their own hardware with links to the burn wire
    circuit, the feet, and the version explainer.
2026-11-09 docs: camera payload card names the V3 kit's Arduino Nicla Vision
2026-11-10 docs: show how to reach the bootloader through the antenna board jumper holes
    The FC Jumpers on the antenna board are bare plated holes, not pin headers,
    so the full kit page now says to bridge them with a bent paper clip and
    shows where they are: a close-up drawn from the antenna board v2c layout,
    and the 3D viewer zoomed to the BOOT SELECT and RESET holes. The viewer
    gains marks: labelled points on a part, listed in parts.json and deep
    linked with ?mark=. It also explains the watchdog window: on a kit with
    JP6 bridged, nothing pets the watchdog in bootloader mode, so the drive
    disappears about 26 seconds after the reset.
    Claude-Sess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
2026-11-10 docs: lock the viewer orbit onto the focus area; watchdog window is 42 s on every kit
    A build step that names its focus, and a ?mark= deep link, now frame the
    camera on that area and lock the orbit pivot there: panning is off and a
    drag that interrupts the flight still lands on the pivot. Steps without a
    focus, part selection and Reset orbit freely as before.
    Every kit ships with JP6 bridged and the watchdog period is about 42
    seconds, so the full kit and flight controller pages say that instead of
    26 seconds on some kits.
    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
2026-11-10 docs: review fixes for the jumper holes page and viewer marks
    Marks now show only when a ?mark= deep link asks for them, so the plain
    antenna board view no longer draws two overlapping labels. Leaving the
    marked view drops the marks, the URL parameter and the orbit lock. The
    marks layer sits under the panels, and a part with marks but no pieces
    no longer breaks loading.
    The full kit page warns that the Batt Charging Bypass holes beside the
    FC Jumpers are wired to the battery, and the drawing crosses them out.
    The drawing gets a light card so it reads in the dark theme, and its
    rotated labels read in the right order. The watchdog note says the kit
    may not start after an interrupted copy, and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
2026-11-11 docs: annotated KiCad render of the top face and an RBF jumper clip on the full kit page
    Meet the top face now opens with the antenna board's outer face rendered
    from the V2c KiCad design, with thirteen numbered callouts that match the
    table. Power on and listen gains a looping clip of the two-pin RBF jumper
    leaving and re-entering the ALT RBF holes.
    The table now names the ALT RBF holes as the RBF location and marks the
    Remove Before Flight Pin Port label as unused on this board.
    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
2026-11-12 docs: name the foot screws and switch plungers on the Fasteners card
